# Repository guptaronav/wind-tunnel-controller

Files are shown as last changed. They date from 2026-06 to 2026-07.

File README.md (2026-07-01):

# Wind Tunnel

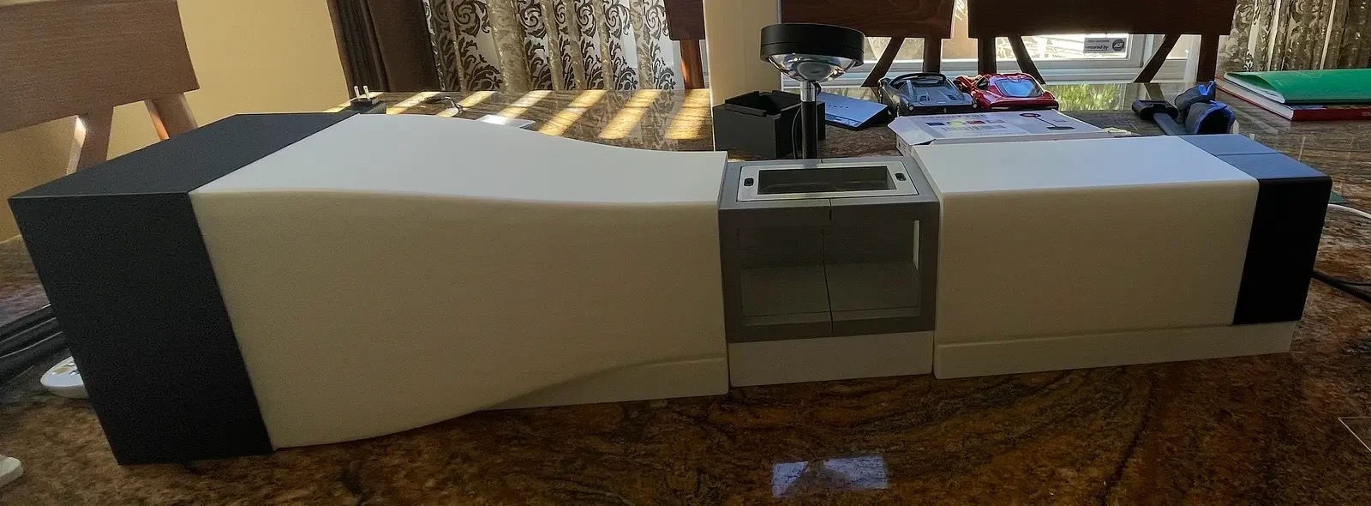
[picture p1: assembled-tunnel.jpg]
Assembled wind tunnel


A desktop open-circuit wind tunnel with fan-driven airflow, mist-based flow visualization, and a knob controller for fan speed. Everything needed to build one is in this repo: the 3D printable parts, the electronics wiring, and the ESP32-C3 firmware.

Rotate the knob to set fan speed — the round display shows the simulated mph of the test object (0–250 mph) in real time and the fan responds instantly over PWM. The mist maker injects visible fog into the airflow so you can see flow behavior through the clear test section.

Explanation/Demonstration: https://drive.google.com/file/d/127fWZjQ2nb-Qn_b_NwKwKz4MTpZqQBtf/view?usp=sharing

---

## Repo layout

```
hardware/
  3d-printed-parts/   STL files for every printed part
  contraction-cone-profile.png   reference curve used to design the contraction cone
  venturi-effect.png  Venturi effect reference diagram
firmware/
  wind-tunnel.yaml     ESPHome config for the fan controller
  secrets.yaml         WiFi credentials (gitignored, create your own)
assembled-tunnel.jpg  photo of the built tunnel
```

---

## Overview

Air is pulled through the tunnel by the fan at the exit end:

```
Mist injected here
       ↓
Honeycomb + screen inlet → Contraction cone → Test chamber → Diffuser → Fan
```

- **Honeycomb inlet / screen inlet** straighten and smooth incoming air, and the mist along with it, before it accelerates through the contraction cone. Mist enters here via the **manifold**, fed by an ultrasonic mist maker housed in the **mister enclosure**.
- **Contraction cone** narrows the flow into the test chamber, increasing velocity and evening out the profile.
- **Test chamber** is where models sit. A **top door** gives access without disassembling the tunnel.
- **Diffuser** widens back out after the test chamber, recovering pressure before the fan.
- The **fan**, mounted at the exit, pulls air through the whole stack and is the only powered/controlled component.

---

## Wind tunnel basics

**What it's for.** A wind tunnel moves air past a stationary object instead of moving the object through still air. That makes it possible to study drag, lift, and flow separation on a scale model without building anything full size.

**Meshes and eddies.** An eddy is a swirling pocket of air that breaks away from the main flow, usually where flow separates around an edge or surface. Eddies make the airflow turbulent and uneven, which ruins flow visualization and skews test results. The honeycomb mesh forces air through a bundle of parallel cells, killing swirl and any sideways motion. The fine screen behind it breaks up the smaller eddies that survive and evens out the velocity across the whole cross-section, since faster-moving air meets more resistance passing through the mesh than slower air does.

**Venturi effect.** Air is effectively incompressible at these speeds, so the same volume has to pass through every cross-section per second. Narrow the duct and the air has to speed up to keep up, the same principle behind a Venturi tube. That's what the contraction cone does: it shrinks the cross-section ahead of the test chamber, accelerating and smoothing the flow before it reaches the model.

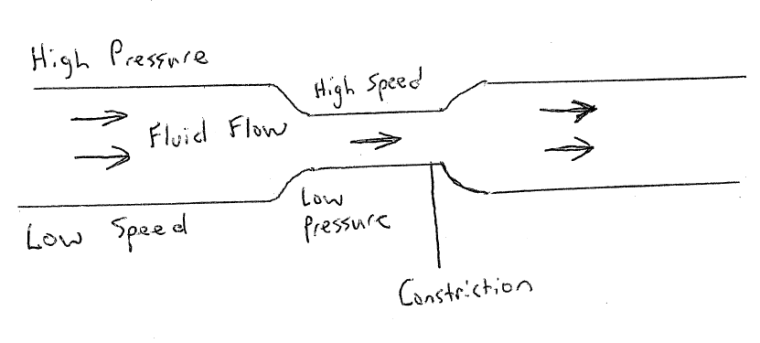
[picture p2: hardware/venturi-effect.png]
Venturi effect: constricting a duct raises speed and drops pressure


**Why a 5th-degree polynomial.** The contraction cone's wall profile (see [`contraction-cone-profile.png`](hardware/contraction-cone-profile.png)) is a quintic curve rather than a plain cone or a cubic, because a 5th-degree polynomial is the lowest degree that can satisfy six conditions at once: matching radius, slope, and curvature at both the inlet and the outlet. Matching slope keeps the wall tangent to the straight duct on each end with no kink. Matching curvature avoids a sudden change in the pressure gradient. Either discontinuity would trip the boundary layer into separating, adding turbulence right before the air reaches the test section.

---

## Bill of materials

### 3D printed (PLA, see [`hardware/3d-printed-parts/`](hardware/3d-printed-parts))

| Part | Qty | Notes |
|---|---|---|
| Base 1 / 2 / 3 | 1 each | Structural base, split into 3 prints |
| Contraction Cone 1 / 2 | 1 each | Two-piece cone, see profile reference image |
| Test Chamber 1 / 2 | 1 each | Two-piece test section |
| Diffuser 1 / 2 | 1 each | Two-piece diffuser |
| Honeycomb Inlet | 1 | Flow straightener, intake side |
| Honeycomb Outlet | 1 | Flow straightener, exit side |
| Screen Inlet | 1 | Mesh screen mount, intake side |
| Screen Outlet | 1 | Mesh screen mount, exit side |
| Top Door | 1 | Test chamber access hatch |
| Manifold | 1 | Distributes mist into the airflow |
| Mister Enclosure Bottom | 1 | Houses the ultrasonic mist maker |
| Mister Enclosure Lid | 1 | — |

### Materials

| Part | Qty | Notes |
|---|---|---|
| Plexiglass (acrylic) sheet | — | Test chamber side panels — transparent and airtight |

### Electronics

| Part | Qty | Notes |
|---|---|---|
| VIEWE UEDX24240013-MD50E (ESP32-C3, round display + rotary encoder built in) | 1 | Fan controller |
| Noctua NF-R8 redux-1800 PWM fan (4-pin, 80mm) | 1 | ~12V, well under 0.1A draw |
| Ultrasonic mist maker module (fogger disc) | 1 | — |
| 12V DC power supply | 1 | — |
| USB 5V adapter | 1 | Powers the controller board |
| Hookup wire, 22–24 AWG | — | Fan and ground wiring |

---

## Wiring

### VIEWE board — internal pin mapping
| Signal | GPIO |
|---|---|
| SPI CLK | 1 |
| SPI MOSI | 0 |
| Display CS | 10 |
| Display DC | 4 |
| Display RST | 2 |
| Backlight PWM | 8 |
| Encoder A | 6 |
| Encoder B | 7 |
| Encoder Button | 9 |

### Fan connection
| Fan wire | Colour | Connect to |
|---|---|---|
| Pin 1 | Black | GND (shared with ESP32 and 12V supply −) |
| Pin 2 | Yellow | 12V supply + |
| Pin 3 | Green | Not connected (tachometer) |
| Pin 4 | Blue | GPIO 21 / TX1 (25 kHz PWM signal) |

> **Important:** The 12V supply negative and the ESP32 GND must share a common ground. Without this the fan will not respond to PWM.

---

## Software setup

### Requirements
- Python 3.8+
- ESPHome

```bash
pip3 install esphome
```

### Configuration

1. Clone this repo:
   ```bash
   git clone https://github.com/guptaronav/wind-tunnel-controller.git
   cd wind-tunnel-controller/firmware
   ```

2. Create `secrets.yaml` (not committed — keep this private):
   ```yaml
   wifi_ssid: "YOUR_SSID"
   wifi_password: "YOUR_PASSWORD"
   ```

3. Compile:
   ```bash
   esphome compile wind-tunnel.yaml
   ```

4. Flash — hold the rotary knob while plugging in USB to enter bootloader mode, then:
   ```bash
   esptool --before default-reset --after hard-reset --baud 460800 \
     --port /dev/cu.usbmodem<PORT> --chip esp32c3 write-flash \
     -z --flash-size detect \
     0x10000 .esphome/build/wind-tunnel/.pioenvs/wind-tunnel/firmware.bin \
     0x0     .esphome/build/wind-tunnel/.pioenvs/wind-tunnel/bootloader.bin \
     0x8000  .esphome/build/wind-tunnel/.pioenvs/wind-tunnel/partitions.bin \
     0x9000  ~/.platformio/packages/framework-arduinoespressif32/tools/partitions/boot_app0.bin
   ```

5. After first flash, OTA updates work wirelessly — just run `esphome run wind-tunnel.yaml`.

---

## How the controller works

```
Rotary Knob (0–100)
       │
       ├──► LEDC PWM output (GPIO 21, 25 kHz) ──► Noctua fan blue wire
       │
       └──► Display redraws simulated mph (Roboto 70pt, GC9A01A via mipi_spi)
```

The rotary encoder maps 0–100 to a 0–100% PWM duty cycle at 25 kHz — the Intel specification for 4-pin PWM fans. That same 0–100 value is linearly scaled to 0–250 mph and rendered with a C++ lambda on the GC9A01A driver, representing the simulated speed of the test object rather than the tunnel's actual (much slower) airspeed — the same idea as a flight simulator showing airspeed independent of real moving air. Both the PWM output and the display update on every encoder tick with no polling loop.

---

## V1 status

V1 is built, assembled, and tested end to end — the mist maker produces visible flow and the knob controller drives the fan. Known improvements for V2:

- Screw mounts for the diffuser fan (currently not secure enough)
- Visual redesign of the test section
- A proper enclosure for the controller and wiring, instead of sitting loose

---

## V2 status

V2 is in the design process and so far, I've redesigned the test section to be one piece, have an L-shaped plexiglass cover, be 150% larger, and allow for better airflow.

Screenshot 2026-07-01 at 2 41 39 PM

---

## Notes

- `secrets.yaml` is gitignored — never commit WiFi credentials
- Use `mipi_spi` platform (not the deprecated `ili9xxx`) for reliable display rendering
- Logger uses `USB_SERIAL_JTAG` to keep GPIO 20/21 free for UART use
- Fan runs below rated RPM on 9V; use 12V for full 1800 RPM
- After flashing, the ESP32 can be powered from any USB adapter — no computer needed

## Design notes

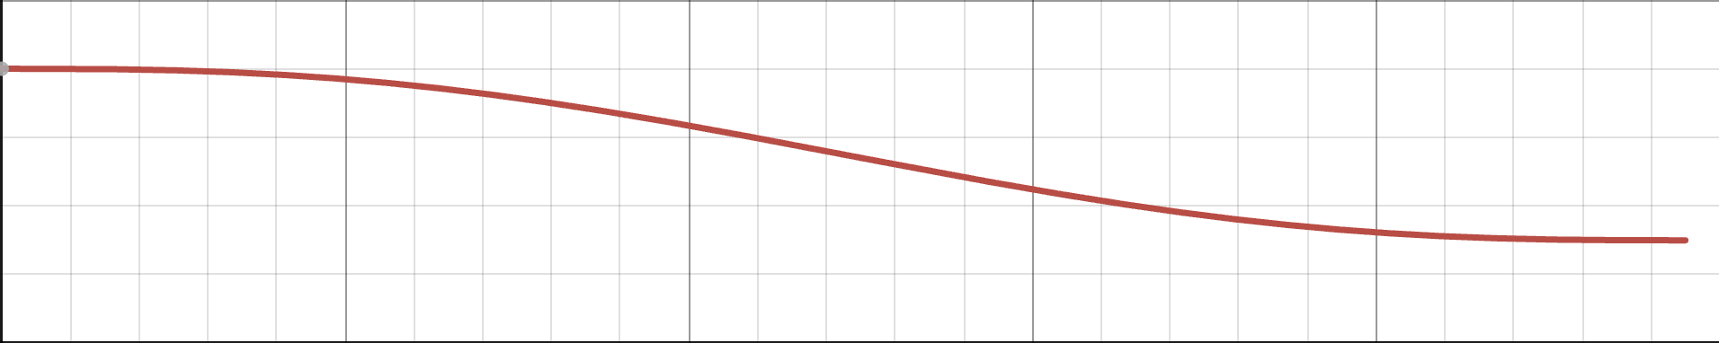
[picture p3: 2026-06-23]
hardware/contraction-cone-profile.png

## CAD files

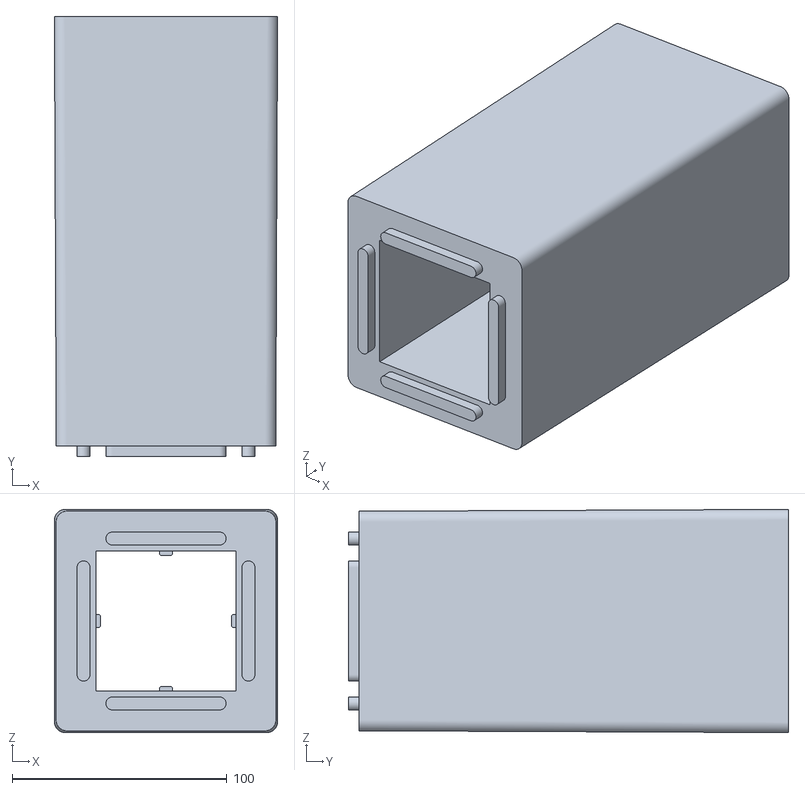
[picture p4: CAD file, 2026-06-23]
hardware/3d-printed-parts/Diffuser 1.stl
104.0 x 205.0 x 104.0

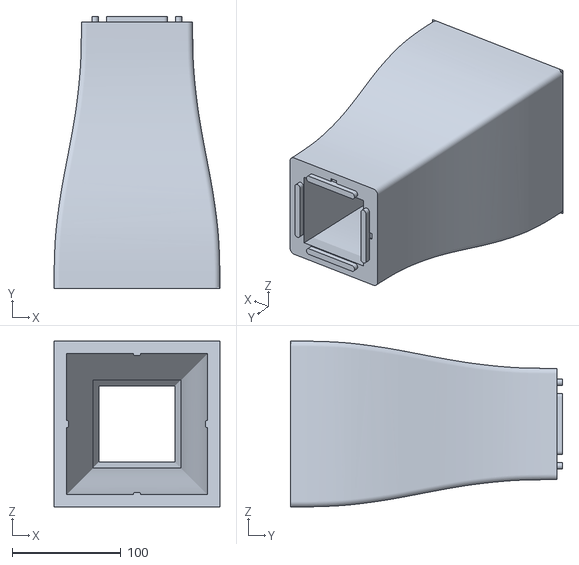
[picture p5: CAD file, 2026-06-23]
hardware/3d-printed-parts/Contraction Cone 2.stl
152.3 x 250.0 x 152.3

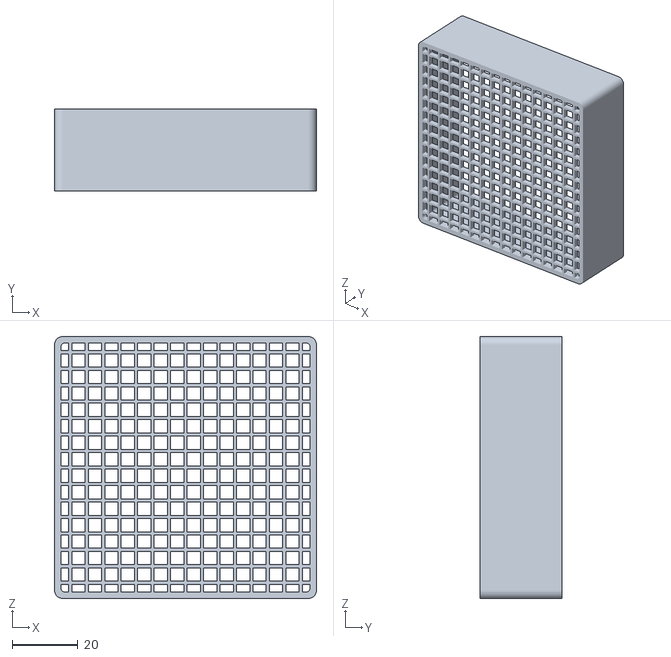
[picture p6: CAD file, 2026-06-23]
hardware/3d-printed-parts/Screen Outlet.stl
79.5 x 25.0 x 79.5

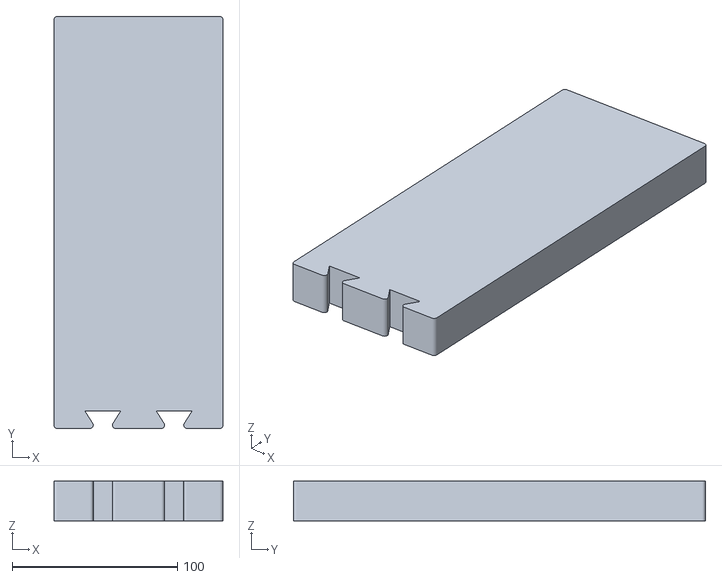
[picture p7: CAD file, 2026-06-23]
hardware/3d-printed-parts/Base 3.stl
102.3 x 249.5 x 24.1

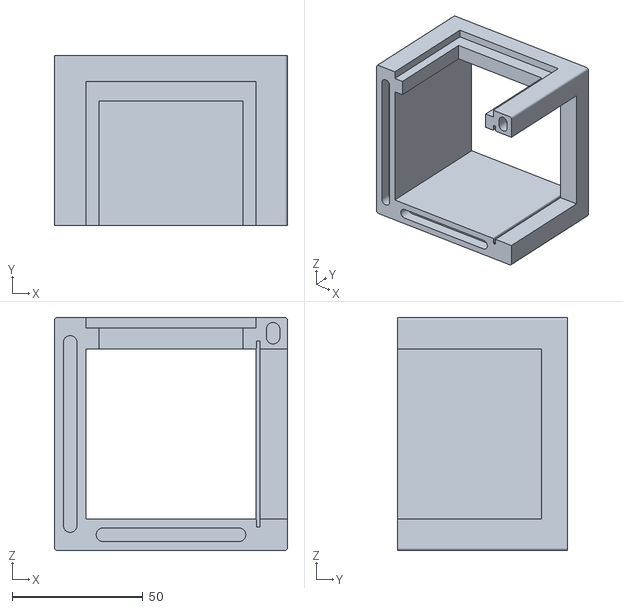
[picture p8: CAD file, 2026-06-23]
hardware/3d-printed-parts/Test Chamber 2.stl
89.0 x 65.0 x 89.0

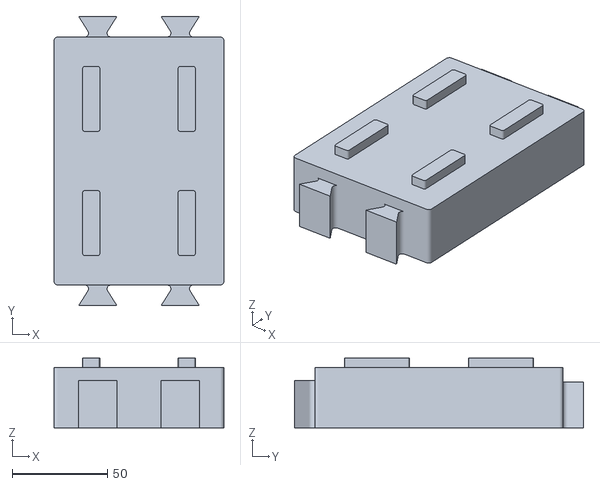
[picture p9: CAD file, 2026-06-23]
hardware/3d-printed-parts/Base 2.stl
89.0 x 151.4 x 36.6

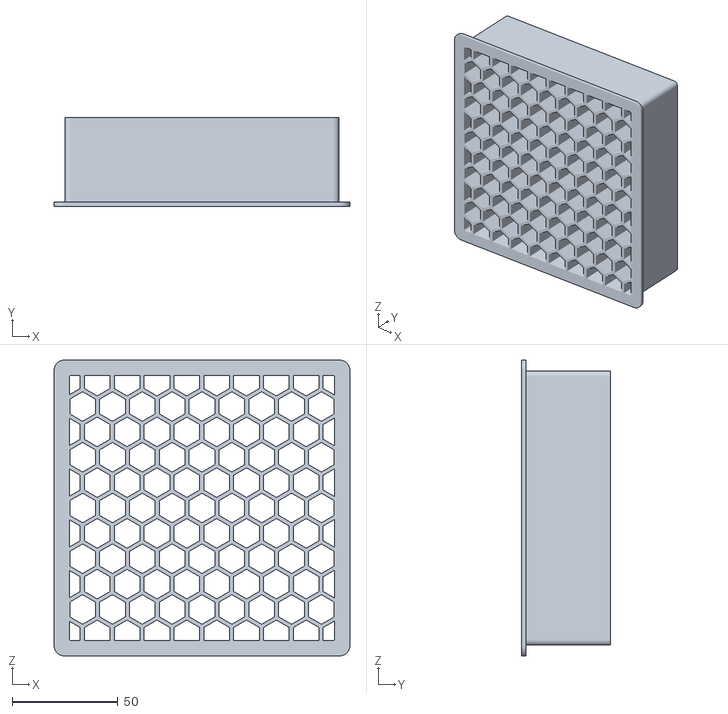
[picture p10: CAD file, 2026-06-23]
hardware/3d-printed-parts/Honeycomb Inlet.stl
140.0 x 42.0 x 140.0

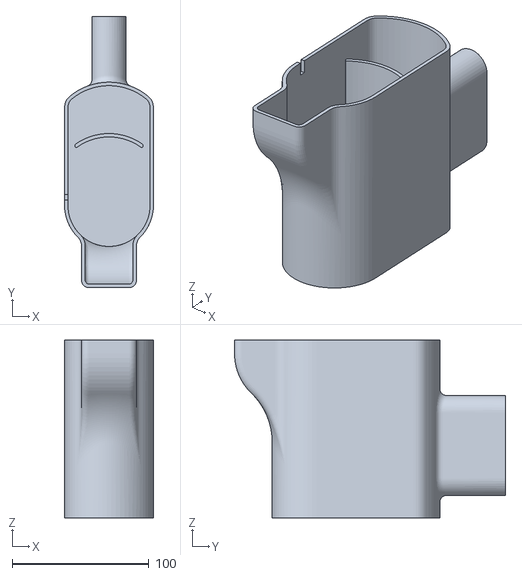
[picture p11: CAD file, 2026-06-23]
hardware/3d-printed-parts/Mister Enclosure Bottom.stl
65.0 x 198.0 x 130.0

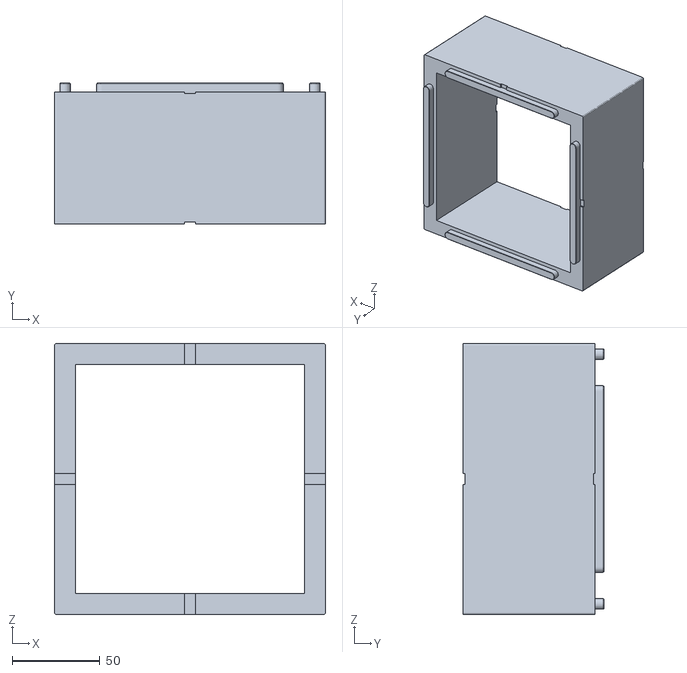
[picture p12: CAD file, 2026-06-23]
hardware/3d-printed-parts/Contraction Cone 1.stl
154.0 x 80.0 x 154.0

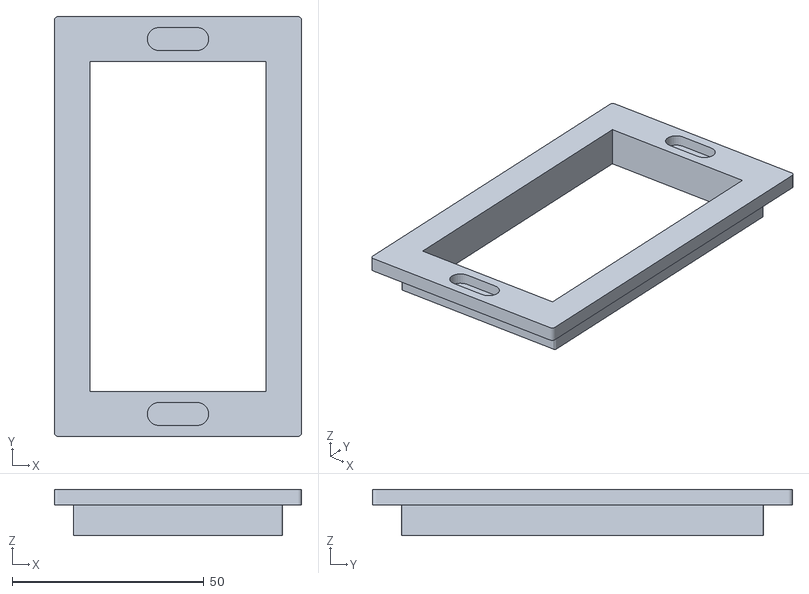
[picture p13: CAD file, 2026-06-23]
hardware/3d-printed-parts/Top Door.stl
64.5 x 109.5 x 12.0

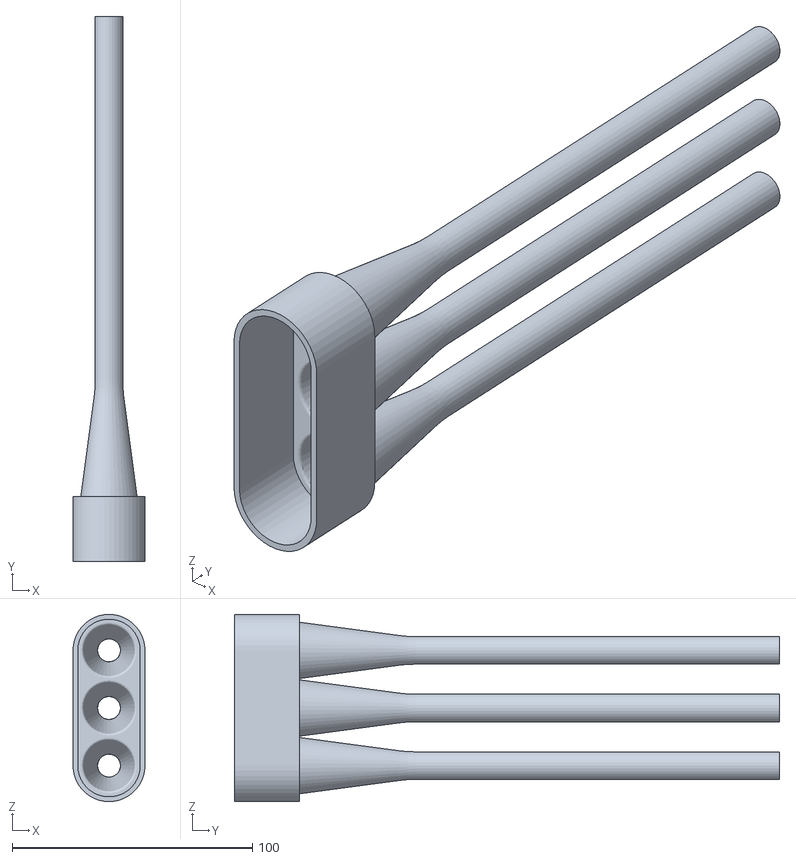
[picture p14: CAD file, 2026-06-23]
hardware/3d-printed-parts/Manifold.stl
30.0 x 227.0 x 78.0

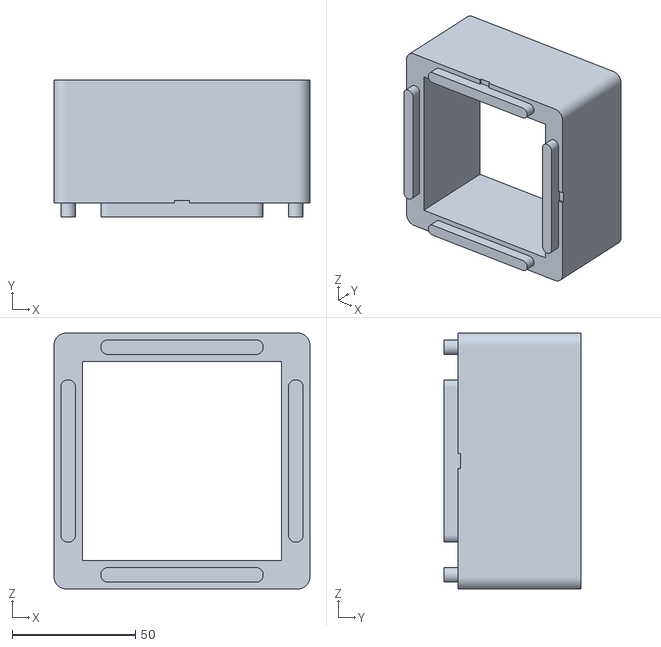
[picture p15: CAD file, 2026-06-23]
hardware/3d-printed-parts/Diffuser 2.stl
104.0 x 55.8 x 104.0

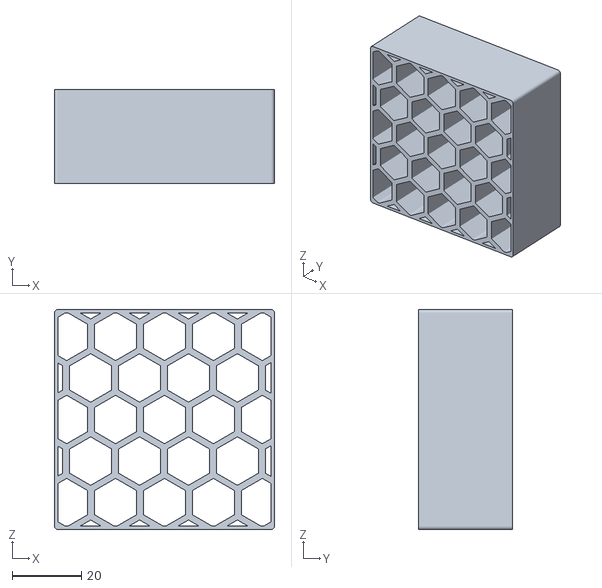
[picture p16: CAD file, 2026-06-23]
hardware/3d-printed-parts/Honeycomb Outlet.stl
63.5 x 27.0 x 63.5

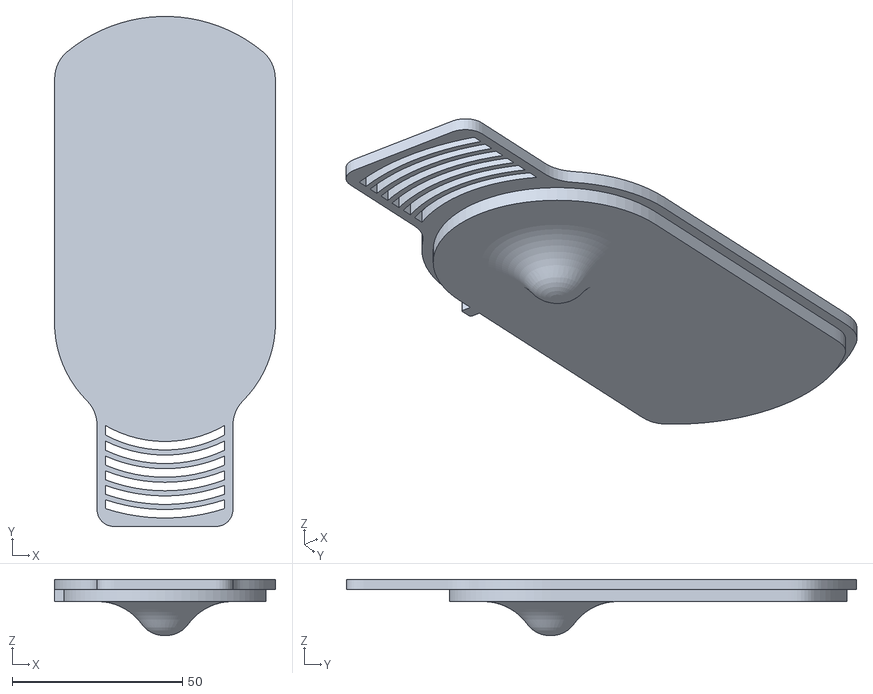
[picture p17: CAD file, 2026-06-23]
hardware/3d-printed-parts/Mister Enclosure Lid.stl
65.0 x 150.0 x 16.5

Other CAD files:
hardware/3d-printed-parts/Base 1.stl
hardware/3d-printed-parts/Screen Inlet.stl
hardware/3d-printed-parts/Test Chamber 1.stl

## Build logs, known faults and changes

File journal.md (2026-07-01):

# Build Journal

A running devlog of progress on the wind tunnel build, oldest to newest.

---

## Devlog #1 — Desktop Wind Tunnel

Hi everyone! For those who don't know, a wind tunnel is a device used to study aerodynamics by passing a controlled airstream over test objects. My goal is to create a fully 3D-printed wind tunnel that's easy to assemble and doesn't require hardware like nuts and bolts.

So far, I've made a 3D-printed mist maker that sits at the inlet, allowing you to actually visualize the airflow as it moves through the tunnel. It looks SUPER cool when flowing around test objects like Hot Wheels cars!

The fan driving the airstream is a Noctua NF-R8 redux-1800, a 4-pin PWM fan that runs on 12V. PWM control allows precise adjustment of the airflow speed. To control the fan, I've built a dedicated electronics controller based on an ESP32, and I plan to integrate everything into the 3D-printed enclosure for a clean, sleek final design.





---

## Devlog #2 — Desktop Wind Tunnel

*17 days ago · 1h 11m 53s logged*

I printed and assembled the test chamber, which is where the test objects sit. I also had to cut acrylic/plexiglass windows to keep the test object visible while having the test chamber sealed for the airstream to flow properly.



---

## Devlog #3 — Desktop Wind Tunnel

*16 days ago · 2h 29m 12s logged*

V1 is done! Unfortunately, my lapse with the slicing, cleaning, and assembly got corrupted, but over these past 2 weeks, I was able to get all parts printed, assembled, and tested. The tunnel runs end to end with the mist maker producing visible flow and the knob controller driving the fan. Testing surfaced a few clear improvements for V2: the diffuser fan needs screw mounts (not secure enough right now), the test section could use a visual renovation (IB: 64 Windsible), and all the electronics need a proper enclosure rather than sitting loose.





---

## Devlog #4 — Desktop Wind Tunnel

*4 days ago · 10h 33m 9s logged*

After the completion of V1, I went in and polished the firmware to look more like the 64 Windsible, so rather than displaying 100%, it'll say 250 mph. This makes the tunnel more fun and gives the user an understanding of what speed the test object would be moving at. I updated the repository to have the CAD files and a better README. I also rewired the circuit to remove the breadboard entirely, making it easier to embed in V2. My next steps are to ship V1 in hopes of going to Outpost and start V2 sometime next week.



---

## Devlog #5 — Desktop Wind Tunnel

*3 days ago · 1h 13m 59s logged*

I didn't change much, but debugged an issue with the mph knob display update where the float value wasn't displaying on the knob properly.



---

Source: https://stardance.hackclub.com/projects/10053

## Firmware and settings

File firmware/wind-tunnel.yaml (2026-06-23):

substitutions:
  # Knob 100% maps to this displayed mph. This is the simulated speed of
  # the test object, not the tunnel's real (much slower) airspeed -- the
  # same way a flight sim shows airspeed independent of actual moving air.
  max_speed_mph: "250"

esphome:
  name: wind-tunnel
  friendly_name: Wind Tunnel Controller
  on_boot:
    - priority: -100
      then:
        - delay: 3s
        - lambda: 'id(startup_complete) = true;'

globals:
  - id: startup_complete
    type: bool
    restore_value: false
    initial_value: 'false'

esp32:
  board: esp32-c3-devkitm-1
  framework:
    type: arduino

logger:
  hardware_uart: USB_SERIAL_JTAG
  baud_rate: 0
api:
ota:
  platform: esphome

preferences:
  flash_write_interval: 1s

wifi:
  ssid: !secret wifi_ssid
  password: !secret wifi_password
  ap:
    ssid: "Wind-Tunnel-Fallback"
    password: "fallback123"

captive_portal:

font:
  - file: "gfonts://Roboto"
    id: font_large
    size: 70
  - file: "gfonts://Roboto"
    id: font_small
    size: 22

color:
  - id: col_blue
    hex: "0096FF"
  - id: col_gray
    hex: "444444"
  - id: col_white
    hex: "FFFFFF"
  - id: col_black
    hex: "000000"

spi:
  clk_pin: 1
  mosi_pin: 0

display:
  - platform: mipi_spi
    model: GC9A01A
    id: round_display
    cs_pin: 10
    dc_pin: 4
    reset_pin: 2
    invert_colors: true
    update_interval: 500ms
    lambda: |-
      float pct = id(knob_encoder).state;
      float mph = pct / 100.0f * static_cast<float>(${max_speed_mph});
      it.fill(Color(0, 0, 0));
      char buf[8];
      sprintf(buf, "%.1f", mph);
      it.print(120, 95, id(font_large), id(col_white), TextAlign::CENTER, buf);
      it.print(120, 160, id(font_small), id(col_white), TextAlign::CENTER, "mph");

output:
  - platform: ledc
    id: backlight_output
    inverted: true
    pin: 8
    frequency: 5000Hz
  - platform: ledc
    id: motor_output
    pin: 21
    frequency: 25000Hz

light:
  - platform: monochromatic
    name: "Backlight"
    output: backlight_output
    restore_mode: RESTORE_DEFAULT_ON

sensor:
  - platform: rotary_encoder
    id: knob_encoder
    name: "Knob"
    pin_a:
      number: 6
      mode:
        input: true
        pullup: true
    pin_b:
      number: 7
      mode:
        input: true
        pullup: true
    resolution: 2
    min_value: 0
    max_value: 100
    restore_mode: RESTORE_DEFAULT_ZERO
    publish_initial_value: true
    on_value:
      then:
        - logger.log:
            format: "Knob: %d"
            args: ['(int)x']
        - output.set_level:
            id: motor_output
            level: !lambda "return x / 100.0;"
        - component.update: round_display

binary_sensor:
  - platform: gpio
    name: "Knob Button"
    pin:
      number: 9
      mode:
        input: true
        pullup: true
      inverted: true
    filters:
      - delayed_on: 50ms
      - delayed_off: 50ms
    on_press:
      then:
        - if:
            condition:
              lambda: 'return id(startup_complete);'
            then:
              - sensor.rotary_encoder.set_value:
                  id: knob_encoder
                  value: 0
              - logger.log: "Knob Button: reset to 0%"

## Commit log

2026-05-15 Initial commit: ESP32-C3 knob display with PWM fan control - Round 1.28" GC9A01A display showing 0-100% via rotary encoder - Noctua NF-R8 PWM fan controlled at 25kHz via GPIO 21 - ESPHome config with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
2026-05-15 Add README with wiring, setup, and project overview
2026-06-08 feat: persist last speed setting across power cycles
    Enable restore_mode + publish_initial_value on the rotary encoder so
    the last knob position is saved to flash and republished on boot,
    restoring fan speed and display percentage automatically.
    Also removes the leftover on_boot override that forced the motor to
    100% on every startup, which was masking the restored value.
    Closes #4
2026-06-08 feat: add button press to reset speed to 0%
    Pressing the rotary encoder's push button now sets the encoder value
    to 0, which republishes through the existing on_value automation —
    stopping the fan and updating the display to 0% in one action.
    Closes #3
    [knob.yaml]
2026-06-08 chore: rename project identifiers to wind-tunnel
    Renames knob.yaml -> wind-tunnel.yaml and updates ESPHome device
    identifiers (name, friendly_name, AP fallback SSID) plus README flash
    instructions and build paths to match the project's actual name —
    "Wind Tunnel Controller" — instead of the original prototyping name
    "knob-display".
    The physical "knob" hardware references (rotary encoder, wiring docs)
    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
2026-06-08 fix: enable internal pull-up on knob button GPIO
    The push-button binary_sensor on GPIO9 had no pull-up configured,
    unlike the rotary encoder's A/B pins which both set pullup: true.
    Without it the line could float when the button is released, causing
    unreliable press detection and preventing the on_press reset-to-0%
    automation from firing consistently.
    Re: #3
    [wind-tunnel.yaml]
2026-06-08 fix: ignore knob button presses during boot to prevent persisted-value reset
    GPIO9 is the ESP32-C3 BOOT strapping pin and gets toggled by the
    bootloader before the app starts, registering a spurious press on the
    Knob Button binary_sensor right after boot. That spurious press fired
    sensor.rotary_encoder.set_value(0), which both reset the display to 0%
    and overwrote the persisted last-value in flash — causing every power
    cycle to restore to 0% instead of the last set speed.
    Add a startup_complete global flag set true 3s after boot (on_boot,
    priority -100) and gate the button's on_press handler on it, so only
    genuine user presses after boot-up trigger the reset-to-zero action.
    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
    [wind-tunnel.yaml]
2026-06-21 docs: add devlog #2 — V1 complete, V2 scope identified
2026-06-23 fix: revert temporary debug baud rate, keep flash write fix
    baud_rate was temporarily set to 115200 to capture serial logs while
    diagnosing the power-cycle persistence regression. Reverting to 0 now
    that flash_write_interval: 1s (the actual fix) is confirmed in place.
    [wind-tunnel.yaml]
2026-06-23 refactor: reframe repo around the whole wind tunnel, not just the controller
    Move firmware into firmware/, add hardware/3d-printed-parts with all
    STL files and the contraction cone profile reference. Rewrite README
    with a project overview, bill of materials, and updated paths.
    [Base 1.stl, Base 2.stl, Base 3.stl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]
2026-06-23 feat: display estimated mph instead of raw knob percentage
    Convert the 0-100 knob value to a top speed of 2.8 mph, derived from
    the fan's rated free-air flow (27.97 m3/h) divided by the test
    chamber's actual 89mm bore via the continuity equation.
2026-06-23 fix: knob 100% now reads as simulated 250 mph test-object speed
    Reframe the mph display away from the tunnel's literal (slow) airspeed
    toward a simulated speed for the object under test, same idea as a
    flight sim's airspeed indicator.
    [wind-tunnel.yaml]
2026-06-23 docs: drop fasteners/misc BOM section and fill-in placeholders
2026-06-23 docs: fix mist injection point in README (inlet, not test chamber)
2026-06-23 docs: add Venturi effect diagram and assembled tunnel photo
2026-06-23 docs: add plexiglass to BOM for test chamber panels
2026-06-23 fix: use static_cast instead of f-suffix for max_speed_mph substitution
    The substituted value (250) has no decimal point, so appending an f
    suffix directly produced an invalid C++ float literal (250f) and broke
    the build. static_cast<float>() works regardless of whether the
    substitution value is an integer or decimal string.
    [wind-tunnel.yaml]
